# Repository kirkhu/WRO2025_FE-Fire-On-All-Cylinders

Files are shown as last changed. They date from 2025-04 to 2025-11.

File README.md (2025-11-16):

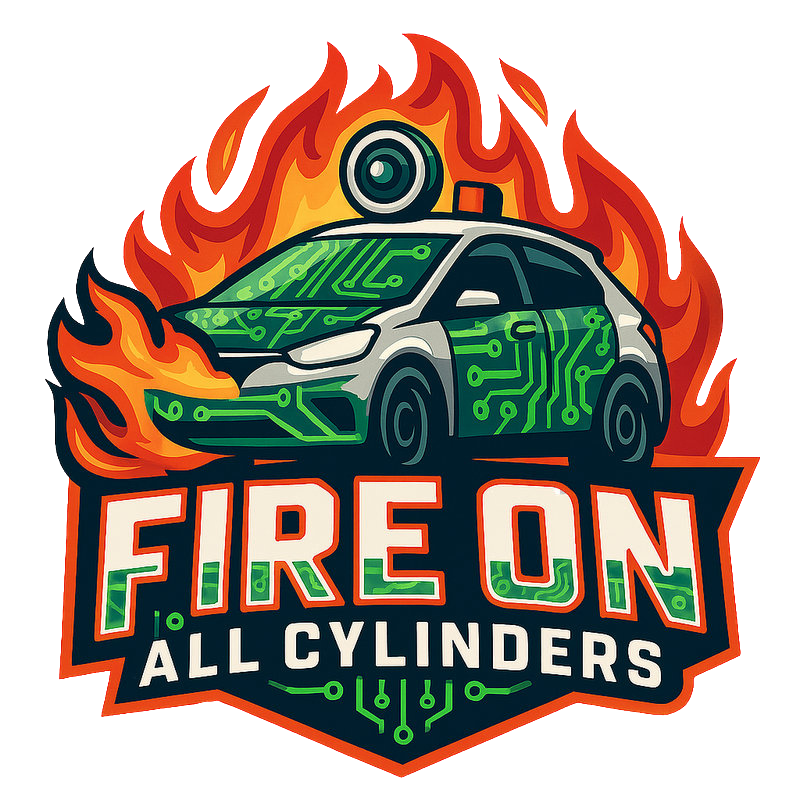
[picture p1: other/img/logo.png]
logo
 

### **Official Technical Document Introduction and Design Overview** 
- This is the official technical documentation for the WRO Taiwan National Team, **"Fire On All Cylinders."**
  
- You can find hyperlinks to the technical report content and setup instructions here, provided for quick access by both learners and judges during study or evaluation.
  
- This technical document will feature a detailed table of contents structured **according to the official scoring criteria** (such as the engineering journal evaluation rubrics), with all section titles displayed as **hyperlinks**. This allows judges or learners to easily navigate to the key content of the technical documentation for **rapid and efficient evaluation**.

### **Autonomous Car Design: Key Upgrades and Iterations** 

 - This autonomous vehicle design is built upon the wealth of experience inherited from our **predecessor team ("Shinan-Fire-On-All-Cylinders")** and integrates the practical experience gained from our participation in the **World Final last year**. Not only have we **drawn lessons from the successful elements of last year's champion team**, but we have also implemented critical technical iterations:
  
    * **Controller Upgrade:** The main controller has been upgraded from the standard **Jetson Nano** to the superior performance of the **Nvidia Jetson Orin Nano**.
    * **Mechanical Overhaul:** We have reorganized and optimized the vehicle's mechanical components, focusing specifically on the **steering system** and the **chassis**.
    * **Visual Enhancement:** Image processing capabilities have been significantly improved, achieving higher **efficiency and accuracy**.
    
    The integration of all these upgrades and innovative design elements is aimed at **comprehensively enhancing the vehicle's overall performance and competitiveness**.

**Special Note:**
- Due to network speed fluctuations, some images may not display correctly. Should this occur, please try refreshing the page to resolve the issue.

#### [For Learners](learners_contents.md)

## Rubric for Judging Engineering Documentation

- ###  ${{\color{red} Hardware Overview }} $ 
  #### 1. Mobility Management
    * [1-1 Vehicle 2D/3D Models in CAD](models/Vehicle_2D_3D/README.md)
    * [1-2 Vehicle Chassis Design](schemes/Vehicle_Chassis_Design/README.md)
    * [1-3 Motor Selection](schemes/Motor/README.md)
  #### 2. Power and Sense Management
    - __2-1 Vehicle Design__
      - [2-1-1 BOM Pats List](schemes/Parts_List/README.md)
      - [2-1-2 Circuit Design](models/Circuit_Design/README.md)
      - [2-1-3 Hardware Fool-Proof Design](schemes/Fool-Proof-Design/README.md)
      - [2-1-4 Assembly Instructions & Wiring Diagrams](schemes/Assembly_Instructions/README.md)
    - __2-2 Power Management__
      - [2-2-1 Battery choice for self-driving cars](schemes/Battery/README.md)
      - [2-2-2 Power Supply System](schemes/Power_Supply_System/README.md)
    - __2-3 Controller Selection__
      - [2-3-1 Main Controller Comparison](schemes/Main_Controller_Choosing/README.md)
      - [2-3-2 Motor & Sensor Intermediate I/O Controller Comparison](schemes/Motor_Sensor_Controller_Choosing/README.md)
    - __2-4 Sense Management__
      - [2-4-1 Ultrasonic rangefinder](schemes/HC-SR04/README.md)
      - [2-4-2 Infrared Sensor](schemes/Infrared-Sensor/README.md)
      - [2-4-3 Gyroscope orientation sensor](schemes/BNO055/README.md)
      - [2-4-4 Camera Selection](schemes/Camera/README.md)

- ### ${{\color{red} Software Overview }} $ 
  #### 3. Obstacle Management
    - [3-1 Software Platform Construction](src/System_Platform_Software/README.md)
    - [3-2 OpenCV Introduction](src/OpenCV/README.md)
 
    - __3-3 Image Recognition Processing and Steering__
      - [3-3-1 Image Recognition Processing](src/Image_Recognition_Processing/README.md)
      - [3-3-2 Parking Lot Departure Steering Control Overview](src/Overview_of_Parking_Lot_Departure_Steering_Control/README.md) 
      - [3-3-3 Steering Control](src/Steering_Control/README.md) 
      - [3-3-4 Automatically record the LAB values of the field](src/Automatically_record_LAB/README.md)
    - __3-4 Programming - Vehicle’s control program__
      - [3-4-1 Open Challenge Code Overview](src/Programming/Open_Challenge/README.md)
      - [3-4-2 Obstacle Challenge Code Overview](src/Programming/Obstacle_Challenge/README.md)
      - [3-4-3 Vehicle Departure Procedure Guide](src/Vehicle_Departure_Procedure_Guide/README.md)
      - [3-4-4 Vehicle Parking Procedure Guide](src/Vehicle_Parking_Procedure_Guide/README.md)
    - __3-5 Remote Connection__
      - [3-5-1 NoMachine software Introduction](other/NoMachine/README.md)

- ### ${{\color{red} Other}} $
  #### 4. Pictures – Team and Vehicle
    - [4-1 Team Members Introduction](t-photos/README.md)
    - [4-2 Vehicle Photos](v-photos/README.md)  
  #### 5. Performance Videos - Challenge rounds
    - [5-1 Open Challenge rounds](video/Open_Challenge/video.md)
    - [5-2 Obstacle Challenge rounds](video/Obstacle_Challenge/video.md)
    - [5-3 Self-Driving Car Design Process Video ](video/Design_Process_Video/video.md)

  #### 6. GitHub Utilization-GitHub
    - [6-1 GitHub Editing Tools Introduction (VScode Edit/GIT)](src/GitHub_Edit/README.md)
    - [6-2 GitHub Web Editor Supported Markup Languages](src/GitHub_Languages/README.md)  
  #### 7. Engineering Factor
    - [7-1 Learning Journey](other/Learning_Journey/README.md)
      - [February](other/Learning_Journey/README.md#20250228--20250307)
      - [March](other/Learning_Journey/README.md#20250308--20250321)
      - [April](other/Learning_Journey/README.md#20250322--20250404)
      - [May](other/Learning_Journey/README.md#20250426--20250502)
      - [June](other/Learning_Journey/README.md#20250531--20250606)
      - [July](other/Learning_Journey/README.md#20250628--20250704)
      - [August](other/Learning_Journey/README.md#20250712--20250822)
      - [September](other/Learning_Journey/README.md#20250830--20250905)
      - [October](other/Learning_Journey/README.md#20250927--20251003)
      - [November](other/Learning_Journey/README.md#20251101--20251107)

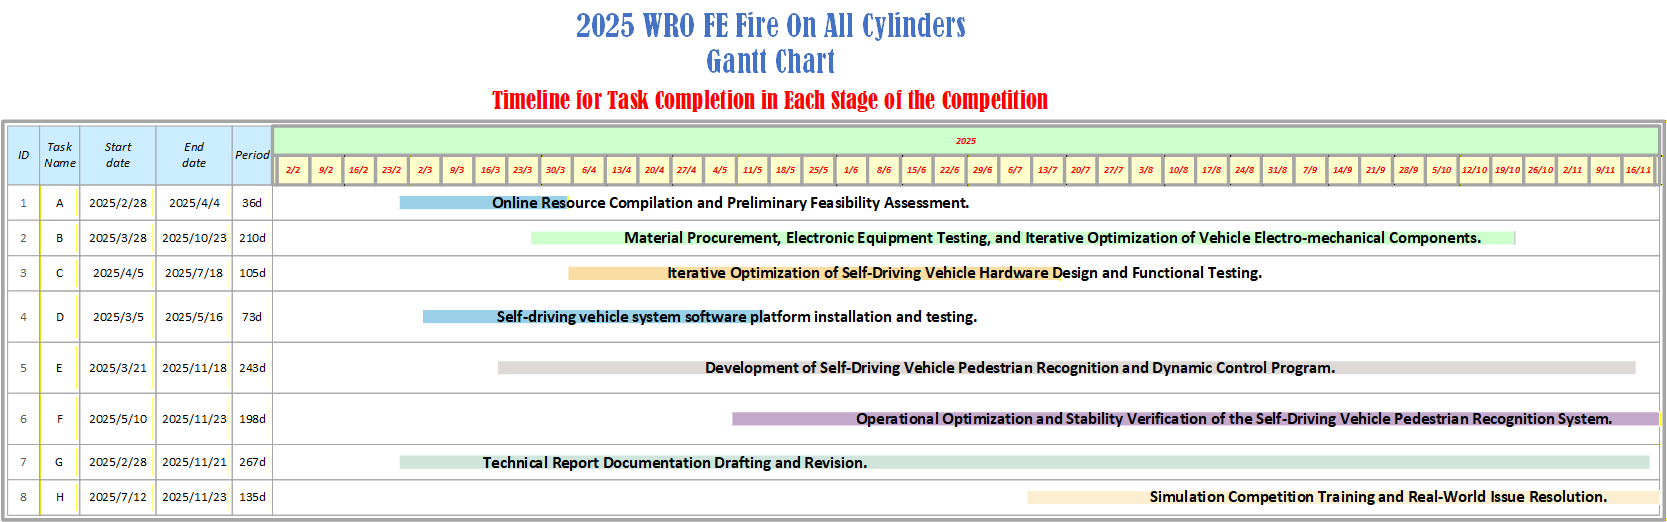
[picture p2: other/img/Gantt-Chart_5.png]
Gantt-Char


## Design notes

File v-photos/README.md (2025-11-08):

<div align="center">logo</div>

## <div align="center"> Vehicle's photos</div>
- ### Vehicle's photos
<div align="center">
<table>
  <tr align="center">
    <th>Top View</th>
    <th>Bottom View</th>
  </tr>
    <tr align="center">
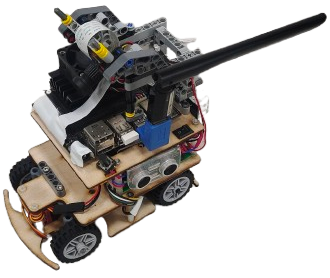
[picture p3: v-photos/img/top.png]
Top view
    <td> </td>
    <td>Bottom view</td>

  </tr>
    <tr align="center">
    <th>Front view </th>
    <th>Rear view</th>
  </tr>
    </tr>
    <tr align="center">
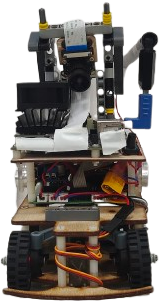
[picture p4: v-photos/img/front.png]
Front_view
    <td></td>
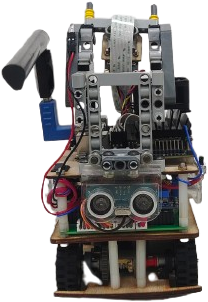
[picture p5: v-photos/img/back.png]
Rear_view
    <td></td>
  </tr>
  </tr>
    <tr align="center">
    <th>Left view</th>
    <th>Right view</th>
  </tr>
    </tr>
    <tr align="center">
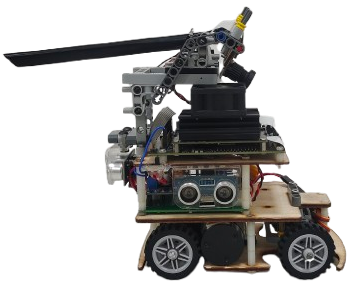
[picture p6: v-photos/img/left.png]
Left view
    <td></td>
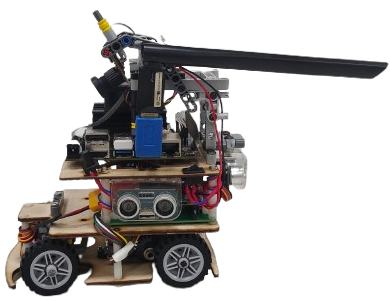
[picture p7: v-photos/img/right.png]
Right view
    <td></td>
  </tr>
</table>
</div> 

- ### Vehicle Body Structure Display Diagram
  <div align="center">
  <table>
    <tr>
    <th>Top View of the Overall Apparatus
    </th>
    <th>Middle Layer Structure Top View</th>
    <th>Top View of Vehicle Chassis</th>
    <th>Bottom View of Vehicle Chassis</th>
    </tr>
    <tr align="center">
      <td>  Top View of the Overall Apparatus
      </td>
      <td>Middle Layer Structure Top View
      </td>
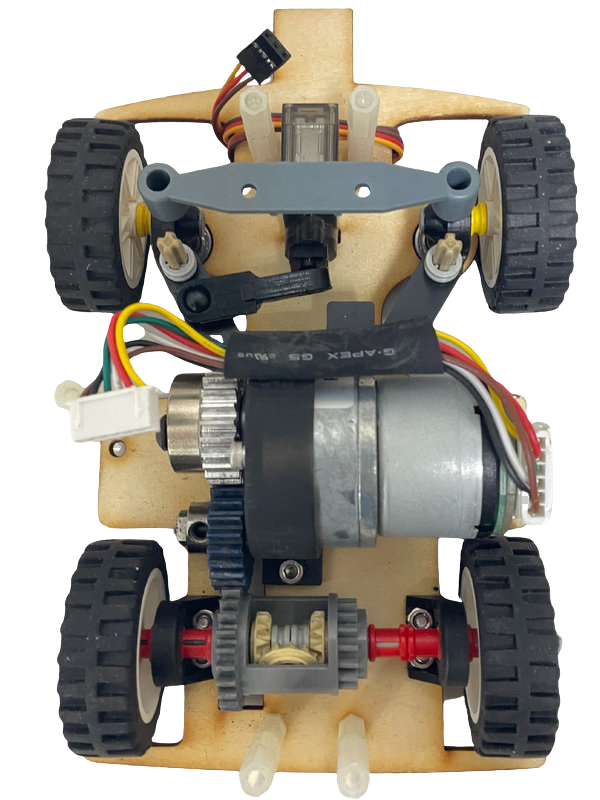
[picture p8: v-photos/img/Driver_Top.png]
Top View of Vehicle Chassis
      <td>
      </td>
      <td>Bottom View of Vehicle Chassis</td>
    </tr>
  </table>
  </div>
- ### Circuit Board
    <div align="center">
    <table>
      <tr align="center">
          <th> Overhead view of the main circuit board</th>
          <th>Overhead view of the switch circuit board</th>
      </tr>
      <tr align="center">
        <td> circuit_up </td>
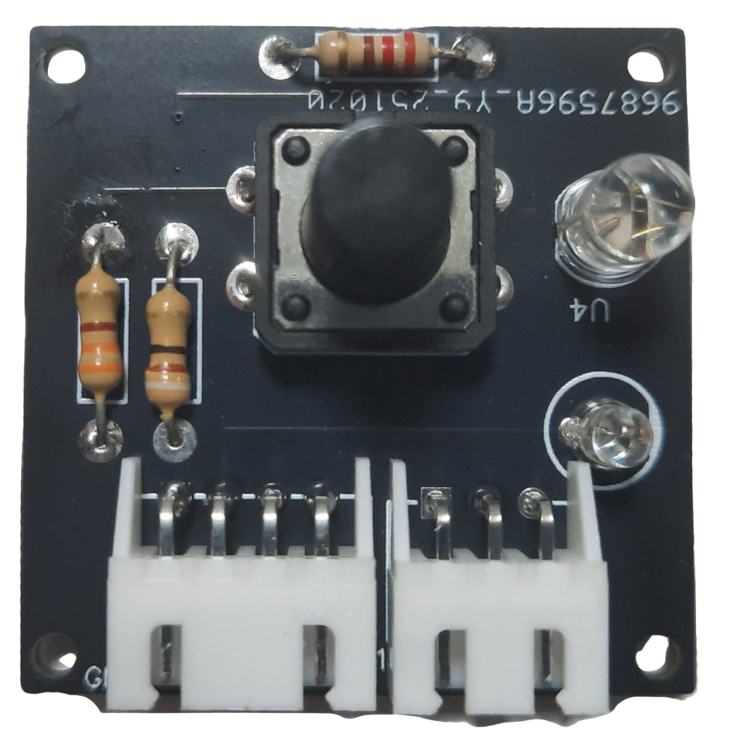
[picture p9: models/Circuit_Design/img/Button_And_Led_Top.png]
circuit_lower
        <td></td>
      </tr>
    </table>
    </div>

# <div align="center">HOME[Return Home](../)</div>

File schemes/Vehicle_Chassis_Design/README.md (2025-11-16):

<div align="center">logo</div>

## <div align="center">Vehicle Chassis Design Process</div> 

### Hardware Design Philosophy and Chassis Optimization
  1.  **Design Legacy and Innovation:** The software and hardware design of this **Self-Driving Car** continues the inspiration from last year's model while **drawing upon the strengths of last year's world champion vehicle design**. Building on this foundation, we upgraded the main controller from the **Nvidia Jetson Nano to the Nvidia Jetson Orin Nano**. This move not only significantly enhances the overall computational performance but also provides a robust basis for introducing innovative software designs, making the vehicle more competitive.

  2.  **Steering Geometry Improvement:** The chassis structure utilizes the common engineering principle of **Ackermann Steering Geometry**. Crucially, we implemented **improvements based on the shortcomings of last year's mechanism**, ensuring the vehicle performs **obstacle avoidance** and **turning maneuvers** with greater stability and smoothness.
  
  3.  **Autonomy of Core Components:** The **vehicle chassis** used in this competition was **independently designed and developed** by our team.
  
- ### Vehicle Chassis Improvement Record

  <div align=center>
  <table>
  <tr>
  <th >2024 Season Competition Self-Driving Car Prototype</th>
  <th  colspan=2 >2025 WRO World Final Competition Prototype</th>
  </tr>
  <tr align=center>
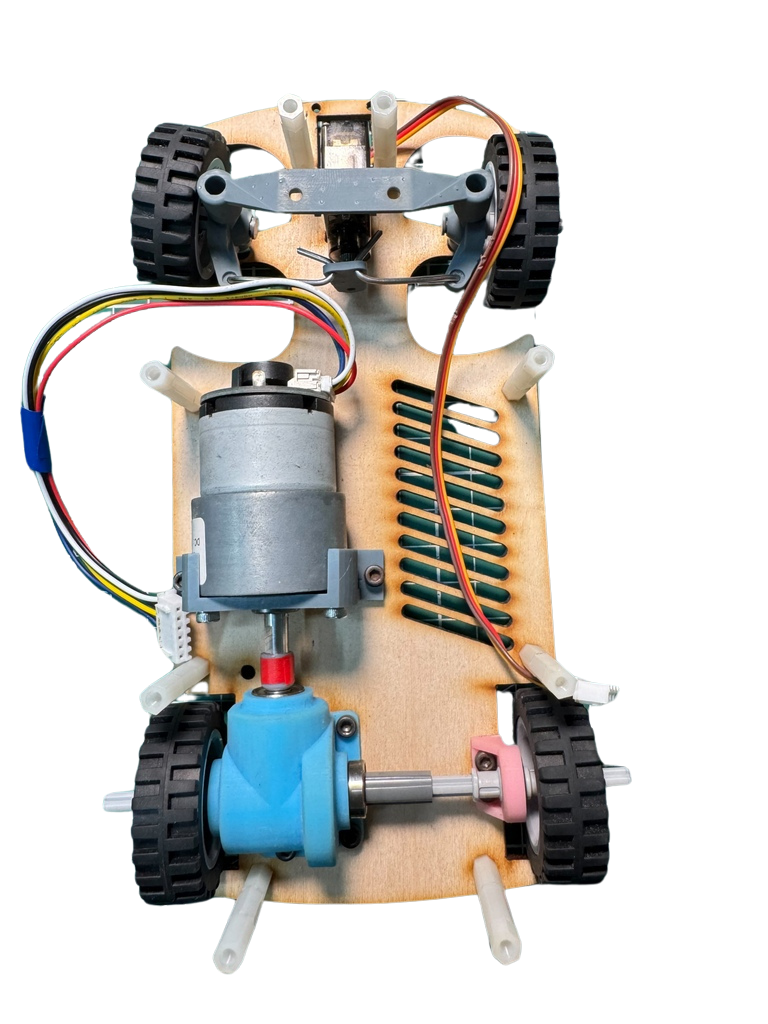
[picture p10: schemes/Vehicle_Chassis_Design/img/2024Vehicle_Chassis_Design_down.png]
2024 Season Competition Self-Driving Car Prototype
  <td width="33%"></td>
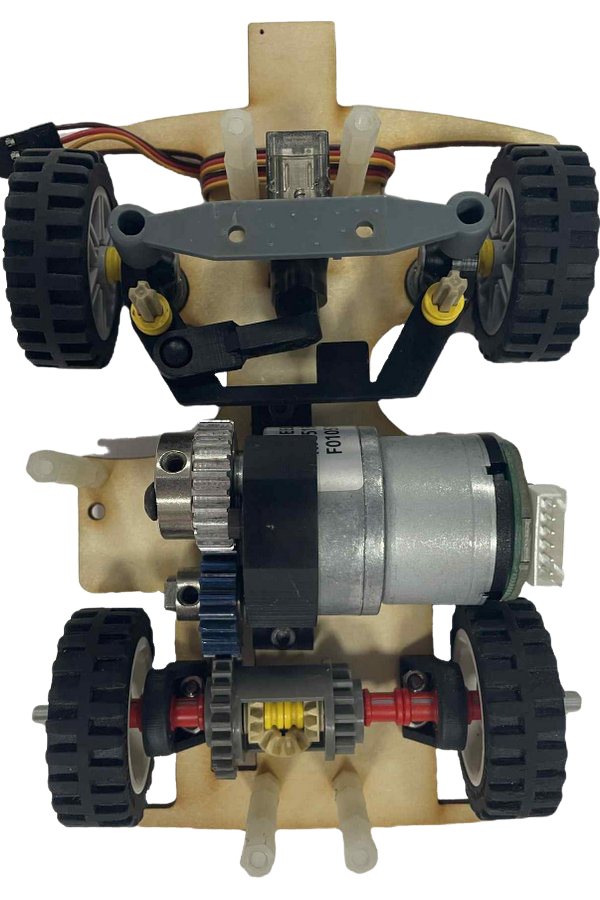
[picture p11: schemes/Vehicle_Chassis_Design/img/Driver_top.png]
  <td width="34%"></td>
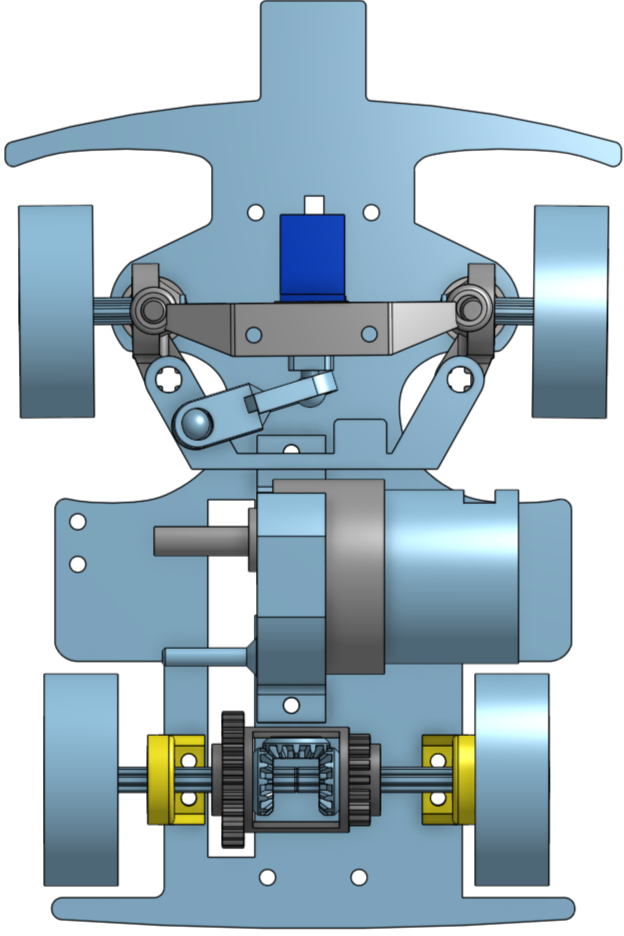
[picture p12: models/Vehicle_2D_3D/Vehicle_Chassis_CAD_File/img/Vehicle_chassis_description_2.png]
  <td width="33%"></td>
  </tr>
  <tr>
  <th colspan=3>Description</th>
  </tr>
  <tr>
  <td colspan="3">

#### **Major Changes in Model and Functionality**

From the previous year's version to this year's international competition version, our model design underwent several key optimizations:

* **Model Size Optimization:** Since the vehicle model was too long, it frequently **moved the field pillars/blocks during obstacle avoidance**. We **shortened the overall length of the model** to enhance obstacle clearance stability.
* **Main Controller Upgrade:** During the National Competition, we found that the **Jetson Nano's computing efficiency** was insufficient for our needs. Consequently, we replaced the main controller with the **higher-computing-efficiency Jetson Orin Nano**.
* **Steering Structure Redesign (I):** Last year's international model used **metal wires** to link the two steering knuckles, which **occupied a large area** and was inefficient. We therefore **redesigned the entire steering structure using 3D printed components**.
* **Steering Structure Redesign (II):** The autonomous vehicle's **steering angle was insufficient**, preventing it from navigating certain **sharp turns**. We **redesigned the steering structure** to allow for a **larger steering space**, enhancing its maneuverability.
* **Addition of Parking Assistance Sensors:** We **added TCRT5000 infrared sensors to the front and rear** of the vehicle, specifically dedicated to **assisting the precision of the parking procedure**.

#### **The Four Iterations of Chassis Design**

Our chassis design underwent a total of four iterations:

1.  **First Iteration:** **Arc-shaped chamfers** were added to the front of the car to prevent the front wheels from **getting stuck** when contacting the side walls, improving self-extrication capabilities after collision.
2.  **Second Iteration:** We **enlarged the mounting holes for the steering knuckles** and **switched to using bearings** to reduce friction, making the steering process **smoother**.
3.  **Third Iteration:** We **reduced the gap** between the steering structure and the motor brackets, and **shortened the wheelbase** to **increase the steering angle** (reducing the turning radius).
4.  **Fourth Iteration:** A **small rectangular block was extended** from the front of the car, specifically to **protect the infrared sensors** from damage during wall collisions.

  </td>
  </tr>
  </table>
  </div> 

**Final Version Vehicle Chassis Design and Physical Product Correspondence**

- The table below presents the clear correspondence between the 3D Model and the final manufactured physical product of our final design version of the Vehicle Chassis.

  |3D Vehicle Chassis Design| Vehicle Chassis Top View | Vehicle Chassis Bottom View|
  |:----:|:----:|:----:|
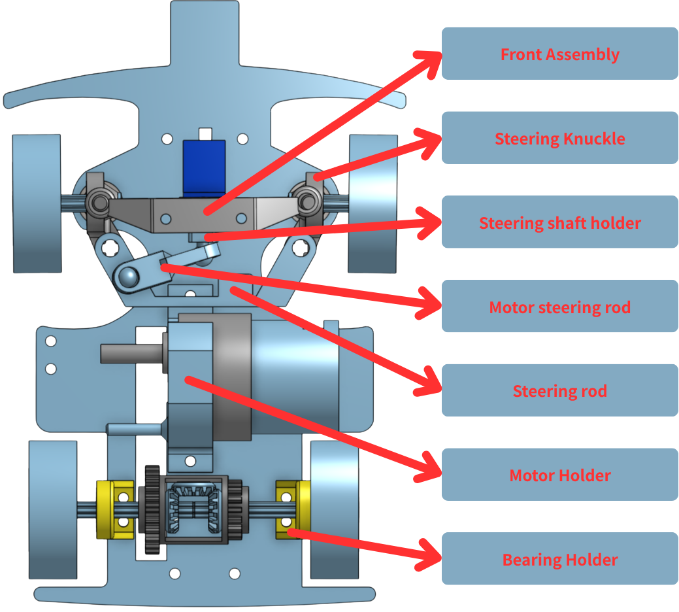
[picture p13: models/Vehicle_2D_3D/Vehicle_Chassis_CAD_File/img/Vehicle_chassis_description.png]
vehicle_chassis_design_3D
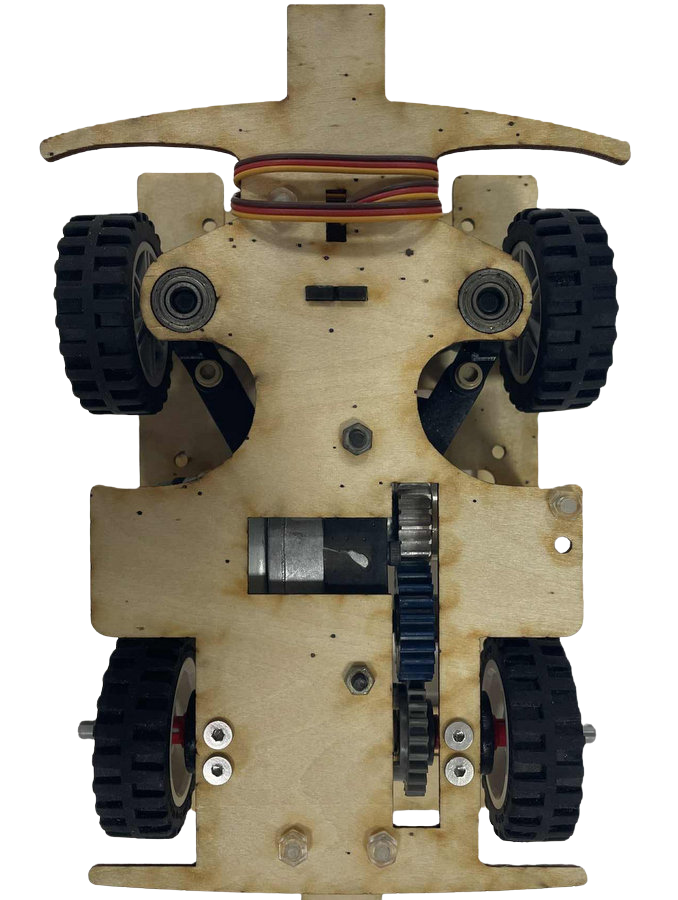
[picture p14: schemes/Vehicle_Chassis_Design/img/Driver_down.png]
down_view
  ||2024Vehicle_Chassis_Design_down||

  - We customized the design of component dimensions and shapes based on the specific performance requirements of the autonomous vehicle. Utilizing a Stereolithography (SLA) 3D printer and a laser cutting machine, we self-designed and manufactured all parts of the vehicle chassis, excluding the gears, the LEGO 6573 differential gear, and the tires.

  - To significantly reduce the rotational friction of the bearings, we - precisely integrated them into the vehicle's support structure (bracket), a mechanical optimization that effectively enhanced the vehicle's overall driving speed.

  - In order to precisely control the vehicle's optimal turning radius and flexibly adjust the Ackermann ratio, we employed 3D modeling techniques and a Stereolithography (SLA) 3D printer to custom-design the critical components and vehicle brackets for the Ackermann steering geometry structure according to specific needs.

**Evolution of the Ackermann Steering Geometry Structure**
  <div align=center>
  <table>

  <tr>
    <th colspan=2>First Generation Steering Structure (V1.0)</th>
  </tr>
  <tr>
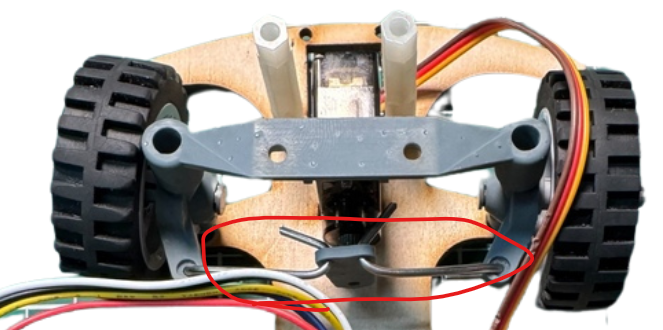
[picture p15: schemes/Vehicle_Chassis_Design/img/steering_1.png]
  <td width=40%></td>
  <td width=60%>

  This version of the steering structure was designed to be overly wide, and the steering rod was made from drawn metal wire, which was difficult to fix into shape, impacting accuracy.

  </td>
  </tr>
  <tr>
    <th colspan=2>Second Generation Steering Structure (V2.0)</th>
  </tr>
  <tr>
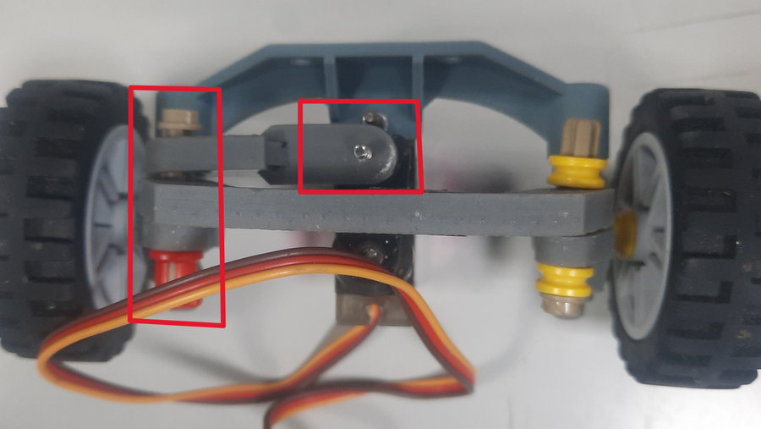
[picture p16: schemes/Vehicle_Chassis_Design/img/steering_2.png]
  <td width=40%></td>
  <td width=60%>
To solve the V1.0 structure's bulkiness and accuracy issues, in V2.0 we:

  - Reduced the overall template size.

  - Replaced the metal wire steering rod with a 3D printed component, significantly improving the rod's accuracy and enhancing the self-driving car's steering agility. However, the use of screws to connect LEGO parts in this version still constrained the steering angle. Therefore, the next iteration (V3.0) will switch to rounded cross axles and Ball Joint Steering Shaft Holder to increase the steering range.
  </td>
  </tr>
  <tr>
    <th colspan=2>Third Generation Steering Structure (V3.0)</th>
  </tr>
  <tr>
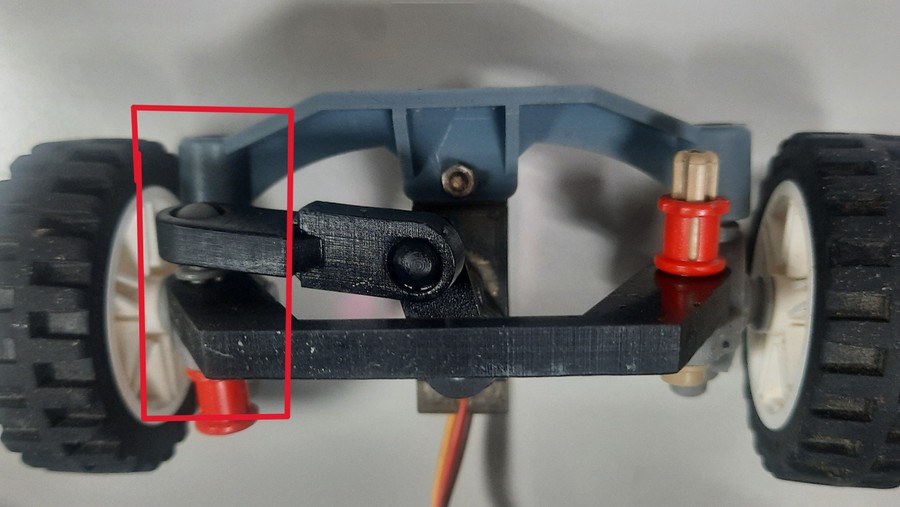
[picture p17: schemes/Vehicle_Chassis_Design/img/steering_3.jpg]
  <td width=40%></td>
  <td width=60%>
  This version encountered steering torque issues during testing, leading us to re-examine the design blueprint. The next version (V4.0) will incorporate the following fixes:

  - Adjust the connection point of the steering tie rod and linkage to be parallel with the rounded steering rack, optimizing mechanical performance.

 - Add a steering limit block to prevent the structure from collapsing inwards due to excessive steering angles.
  </td>
  </tr>
  <tr>
    <th colspan=2>Fourth Generation Steering Structure (V4.0)</th>
  </tr>
  <tr>
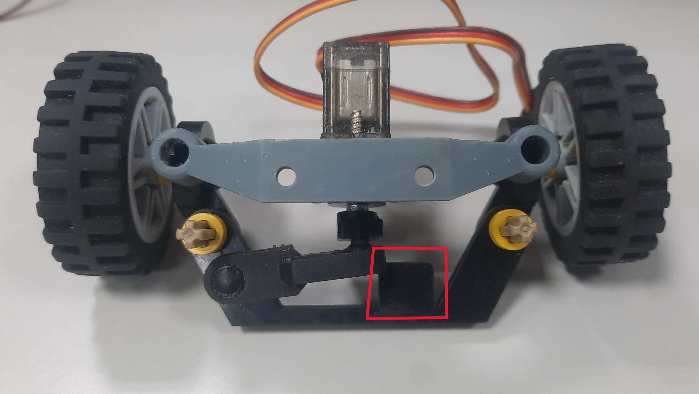
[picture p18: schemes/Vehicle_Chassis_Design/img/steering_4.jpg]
  <td width=40%></td>
  <td width=60%>

  The newly added steering limit block in this version was oversized, which inadvertently restricted the steering angle and reduced the steering agility. Therefore, in the subsequent version (V5.0), we will shorten the limit block to balance both the steering amplitude and structural protection.
    </td>
    </tr>
  <tr>
    <th colspan=2>Final Version Steering Structure (V5.0)</th>
  </tr>
  <tr>
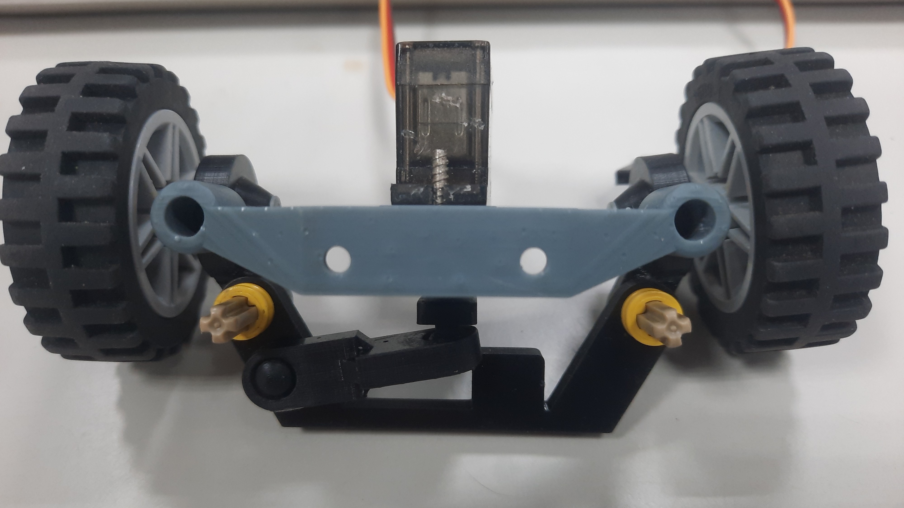
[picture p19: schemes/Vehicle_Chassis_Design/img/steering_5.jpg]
    <td></td>
    <td width=400>
   Following continuous correction and optimization across the previous generations, the current steering structure fully meets the performance requirements of our vehicle model, achieving a stable design state.
    </td>
  </tr>
  </table>
  </div>

- ####  Selection and Modification of LEGO Differential Gears

  The gear differential is a critical core component of a vehicle's drivetrain , used to balance and precisely distribute power to the driving wheels.

  It enables the driving wheels to rotate at different speeds , which is especially crucial during turns. The differential achieves this function through a series of precisely engineered gear mechanisms , allowing the two driving wheels to adaptively adjust their rotational speeds. This capability is vital for enhancing the vehicle's agility and handling. Regardless of road conditions, the differential ensures the vehicle's stability and balance, thereby maintaining excellent driving performance.

  - #### Application and Comparison of LEGO Differential Gears
      In this competition, we utilized LEGO differential gears to implement the core functions of vehicle driving and turning. These differential gears primarily come in two models: the LEGO 6573 Differential and the LEGO 62821 Differential.

    __LEGO 62821 Differential__
      - Composition: This differential consists of one 28-tooth outer gear and four LEGO 12-tooth bevel gears (part number 4565452).

      - Design Advantages: Its compact, enclosed casing design enhances durability and torque transfer efficiency. The central structure securely holds the bevel gears in place, ensuring smooth power distribution to the two output shafts.

      - Performance Positioning: This makes it more efficient and reliable than the older LEGO 6573 Differential.

    __LEGO 6573 Differential__
      - Composition: This differential integrates one 16-tooth gear and one 24-tooth gear. Both gears feature a 5 mm diameter hole at their center for easy cross axle installation.

      - Structural Features: The center of the differential includes a small pillar designed to better secure the right-angle bevel gears, and it can be used in combination with three LEGO 12-tooth bevel gears (part number 4565452).

      <div align=center>
          <table>
          <tr align=center>
          <th>LEGO 62821 GearDifferential</th>
          <th >LEGO 6573 Gear Differential</th>
          </tr><tr align=center>
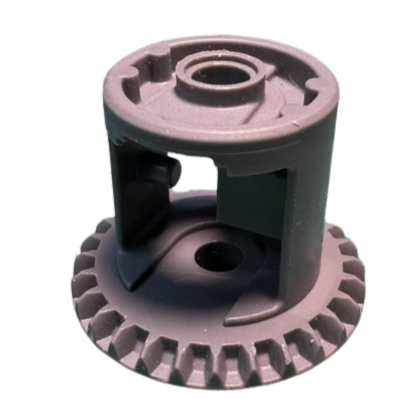
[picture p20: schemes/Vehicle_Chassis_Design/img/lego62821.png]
          <td></td>
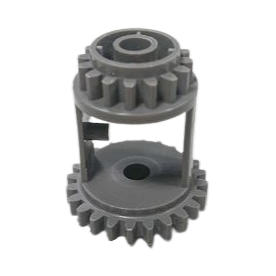
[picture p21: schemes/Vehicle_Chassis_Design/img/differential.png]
          <td></td>
          </tr>
          </table>
          </div>

  - #### Reason for Selection

    - We initially incorporated the LEGO 62821 differential gear as a component in our steering system. However, during the process of meeting the design goal of reducing the chassis dimensions, we discovered that this differential occupied excessive space, making it incompatible with the new structural constraints.

    - Consequently, despite the LEGO 62821 differential gear offering superior steering performance, we chose to abandon it in favor of the smaller LEGO 6573 differential gear. This substitution successfully resolved the structural issue related to the required chassis size reduction, allowing us to achieve a compact vehicle design.

        <div align="center">
        <table>
        <tr>
        <th>LEGO 62821 Gear Differential </th>
        <th>LEGO 6573 Gear Differential </th>
        </tr><tr align=center>
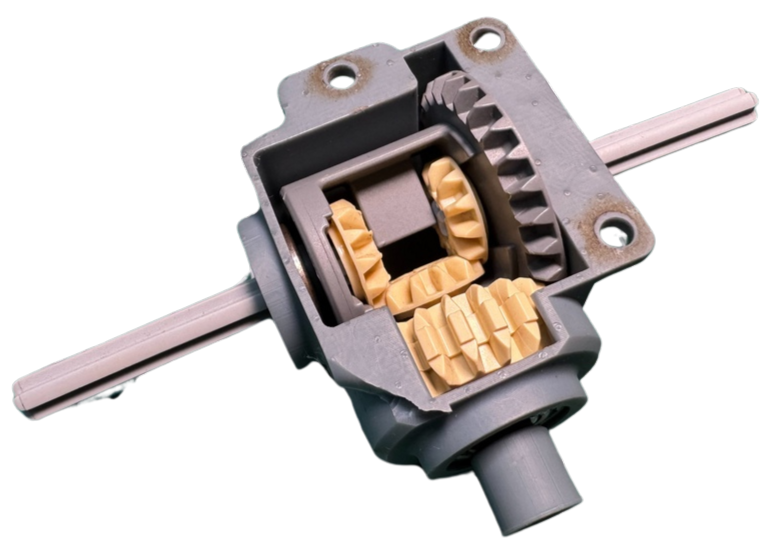
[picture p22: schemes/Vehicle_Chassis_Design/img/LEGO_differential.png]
        <td></td>
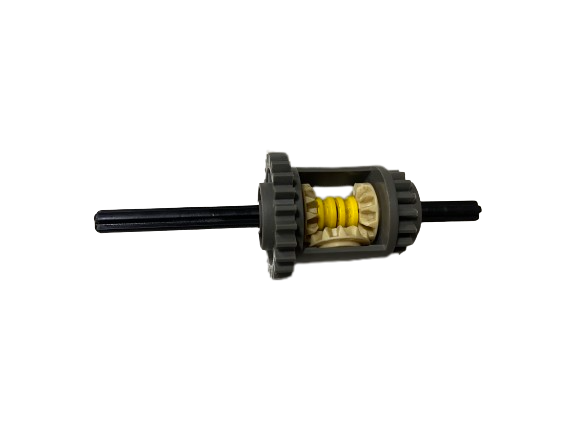
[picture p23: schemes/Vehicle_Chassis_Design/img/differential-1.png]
        <td></td>
        </tr>
        </table>
        </div>

- ### Supplementary information

   - #### What is an Ackermann Steering Geometry?
     __Ackermann Steering Geometry Introduction__
      - The Ackermann steering geometry, proposed by German automotive engineer Lankensperger in 1817, is a steering system design used in automobiles. It was developed to address the geometric discrepancy in the paths of the inner and outer turning wheels when a vehicle makes a turn.
      - People apply Ackermann steering geometry to the steering mechanism of vehicles. Through the corresponding cranks of the four-linkage system, the steering angle of the wheels relative to the projected tire is increased by about 2 to 4 degrees. This results in the rough convergence of the trajectory centers of all four wheels along the extension line of the rear axle, thereby achieving the vehicle's turning.
      
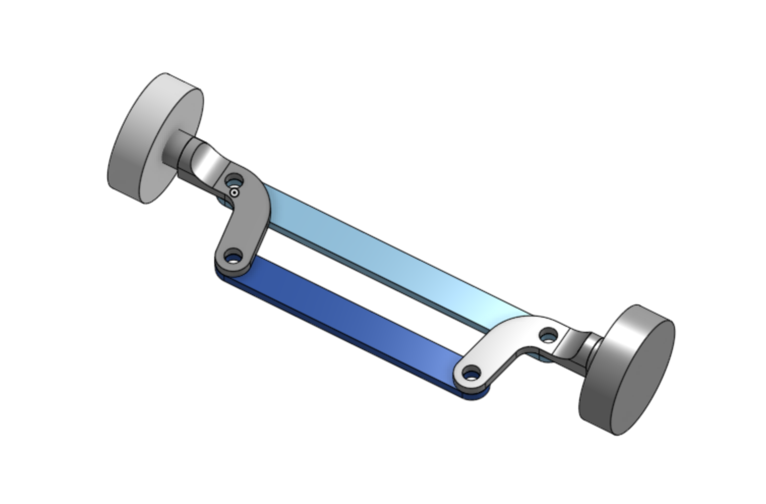
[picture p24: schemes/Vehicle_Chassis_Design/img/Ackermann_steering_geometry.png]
Ackermann_steering_geometry
        

      Reference Link：[Ackermann steering geometry@Wikipedia](https://zh.wikipedia.org/zh-tw/%E9%98%BF%E5%85%8B%E6%9B%BC%E8%BD%89%E5%90%91%E5%B9%BE%E4%BD%95)
      
    -  #### The principle of Ackermann steering geometry is based on the following concepts:     
       - __Difference in Turning Radius:__ When the vehicle makes a turn, the two front wheels need to rotate at different angles to allow the vehicle to pivot around a central point.
       - __Turning Angles of the Two Front Wheels:__ The design of the Ackermann steering geometry ensures that both front wheels pass through a central point simultaneously during steering.
    - Compared to the Ackermann steering geometry made from the original 0% LEGO bricks, the steering mechanism of this competition vehicle is designed with reference to an 80% Ackermann steering geometry. It offers advantages such as reduced resistance and smoother turns. The Ackermann steering geometry parts are produced using a stereolithography (SLA) 3D printer. However, the most challenging aspect of the process was adjusting the Ackermann ratio to achieve the ideal turning angle for our vehicle to navigate around blocks effectively.  

  - #### Why Choose an 80% Ackermann Ratio?
    - In theory, this design is the optimal choice for smooth and efficient turns. However, it may lead to excessive tire wear. Therefore, in automobile design, a 100% Ackermann ratio is usually not chosen. Compared to a 100% Ackermann ratio, an 80% Ackermann ratio allows for smoother, more predictable turns, improves maneuverability, and reduces tire wear.
  
    - #### Calculating the Ackermann Angle Graphically (a-b = ack)
    <div align="center">
    <table>
    <tr align=center>
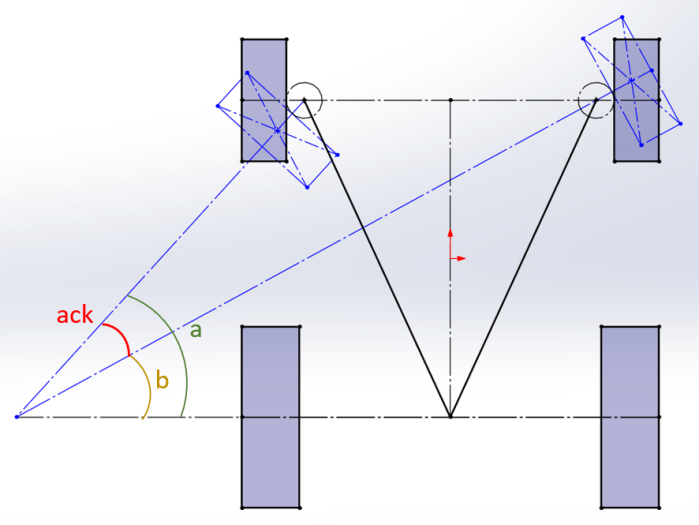
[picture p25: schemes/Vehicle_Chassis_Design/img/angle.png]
angle
    <td width="30%"></td>
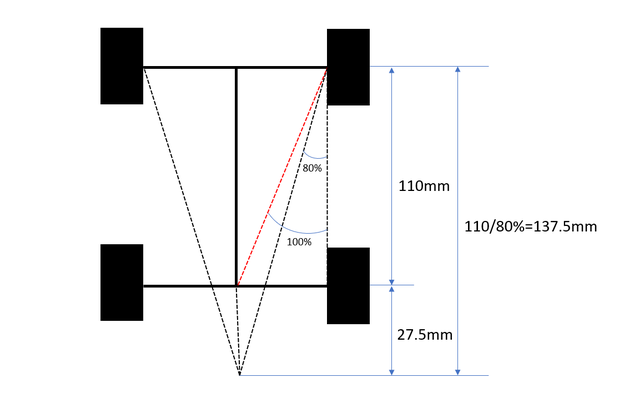
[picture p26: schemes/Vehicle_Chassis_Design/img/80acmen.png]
Ackermann_steering_geometry_lego
    <td width="30%"></td>
    </tr>
    </table>
    </div>

    Reference Video website：[汽车转弯 没那么简单: 阿克曼转向几何是个啥？How does Ackerman steering geometry work?](https://www.youtube.com/watch?v=8AimxDPWKcM)

# <div align="center">HOME[Return Home](../../)</div>

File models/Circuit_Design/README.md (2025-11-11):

<div align="center">logo</div>

 ## <div align="center"> Circuit Design </div>

- In the design process of our **Self-Driving Car** circuit board, we utilized **EasyEDA**, a professional circuit design software featuring an **intuitive graphical interface**. Through this tool, we have **significantly enhanced** the **accuracy** of soldering and the **precision** of wiring, thereby **effectively reducing** the error rate during the manufacturing process, and minimizing the **risk of component burnout**.

- We adopted a **professional Printed Circuit Board (PCB) manufacturing method** (i.e., "PCB etching/fabrication"). This approach has not only **substantially mitigated** the **potential risks** of soldering errors and short circuits but has also **improved the aesthetic quality of the finished product**. Concurrently, this manufacturing technique offers **greater process flexibility** and **operational convenience**.

- The **core function** of this circuit board is to provide a stable and reliable **power supply** and **signal transmission interface** for the **integrated** various **sensors**, **motors**, and the **upper and lower layer controllers**. This ensures that all critical electronic components can achieve **smooth communication** and **efficient collaborative operation**, laying a solid foundation for the execution of the **Vehicle's control program**.

 - ### The Process of Identifying and Correcting Physical Circuit Board Design Issues 
   - ### Circuit Design Optimization and Iteration
   The circuit design for this project underwent several versions to achieve maximum performance and reliability:
<div>
<table>
   <tr>
      <th colspan=3 >Initial Phase and Fundamental Design Flaws V1.0 (Pegboard)</th>
   </tr>
   <tr>
      <td align=center  width="25%"></td>
      <td align=center  width="25%"></td>
   <td>

   __Description:__          

   - This design utilized a PCB pegboard (also known as a universal PCB) as the material for circuit construction. However, this choice resulted in an extremely time-consuming process for circuit design and soldering. Furthermore, the wiring layout appeared cluttered, lacking systematic planning and aesthetic quality. This not only severely hindered the efficiency of subsequent debugging and fault diagnosis, but also posed significant circuit reliability risks, including issues like cold solder joints, poor soldering, and short circuits.
               
   </td>
   </tr>
   <tr>
      <th colspan=3>Adopting Professional Fabrication and Discovering Parameter Errors V2.0 (PCB)</th>
   </tr>
   <tr>
      <td align=center width="25%" ></td>
       <td align=center  width="25%"></td>
      <td>

   __Description:__

   - In order to resolve the various issues present in the old circuit board design (V1.0), we utilized EasyEDA software to redraw the circuit and generate a new Printed Circuit Board (PCB) layout (V2.0). We then submitted this design for professional manufacturing at a factory. This comprehensive process allowed us to successfully acquire industry-standard knowledge of PCB design and fabrication.

   - The team was highly excited upon receiving the factory-produced V2.0 PCB. However, during the component installation phase, we discovered that the electronic components could not be properly assembled. After careful inspection and verification, we confirmed that this was a design error caused by incorrectly setting the component's pin header pitch during the PCB design stage.
            
   </td>
   </tr>
   <tr>
      <th colspan=3>Critical Polarity Error and Subsequent Rectification V3.0 (PCB)</th>
   </tr>
   <tr>
      <td align=center width="25%"></td>
      <td align=center width="25%"></td>
   <td>

   __Description:__
      
   - Given the incorrect component pin pitch issue found in the previous PCB version (V2.0), we immediately referenced the standard example diagrams built into the EasyEDA software to precisely recalibrate the correct pin pitch parameters. We then sent this revised design (V3.0) to the factory for production.

   - However, upon receiving the factory-produced V3.0 PCB and proceeding with the functional testing phase, we discovered that the polarity of the entire circuit was reversed. After detailed circuit tracing and inspection, we ultimately confirmed that this problem stemmed from an operational error during the circuit board design stage: we mistakenly drew the trace layer that should have been on the bottom layer of the PCB onto the top layer.

   </td>
   </tr>
   <tr>
       <th colspan=3>Critical Polarity Error and Subsequent Rectification V4.0 (PCB)</th>
   </tr>
    <tr>
      <td align=center  width="25%"></td>
      <td align=center width="25%"></td>
   <td>

   __Description:__

   - Addressing the issue of reversed circuit polarity in the previous PCB version (V3.0), we performed a complete redraw of the schematic. Only after multiple strict verifications to ensure the design was correct did we submit the file for production, resulting in the accurate Printed Circuit Board (V4.0).

   - Subsequently, due to upgrading the robot's main controller to a Jetson Orin Nano and deciding to switch to infrared sensors for detecting proximity to the parking area walls, it became necessary to add two 2-Pin female connectors to the circuit board. Simultaneously, we redesigned the terminal blocks to provide a stable, plug-and-play power connection point for the Jetson Orin Nano. Based on these functional changes and upgrades, we were compelled to redesign the circuit and submit the new board version (V5.0) to the factory for re-printing.

   </td>
   </tr>
   <tr>
      <th colspan=3>Functional Upgrades and Final Circuit Architecture V5.0 (PCB)</th>
   </tr>
   <tr>
      <td align=center width="25%" ></td>
      <td align=center width="25%"></td>
   <td>
      
   __Description:__

- Correction of BNO055 Gyroscope Sensor Anomaly
Upon obtaining the new Printed Circuit Board (V5.0), testing revealed an intermittent issue where the BNO055 gyroscope sensor would return an angle reading of zero. Troubleshooting confirmed that this anomaly stemmed from the sensor's VCC/GND being supplied by the Raspberry Pi Pico W, while its signal lines were connected to the Jetson Orin Nano main controller. This configuration, where the power and signal sources were on different circuits (i.e., lacking a common ground reference), caused the sensor to malfunction. We immediately revised the design, ensuring that both the power and signal sources for the BNO055 gyroscope sensor are now supplied exclusively by the Jetson Orin Nano main controller to establish a stable electrical potential reference.

- Independent Switch Control Circuit Board (Secondary PCB)
Furthermore, to comply with the competition rule requiring the Jetson Orin Nano to detect the start button press before operation can begin, we designed a second, independent circuit board:
   - Start Button Integration: The start button circuit was independently connected to the Jetson Orin Nano's General-Purpose Input/Output (GPIO) interface, ensuring the main controller detects the start command as per regulations.
   - Debugging and Status Display: To optimize the debugging process, we added RGB LEDs to this board.
   - Functional Purpose: The LEDs are used to display the color of the nearest object detected by the vehicle in real-time, facilitating quick diagnostics and status monitoring.
   - This board is dedicated to the self-driving car's start button control and status indication.

   </td>
   </tr>
     </table>  
  </div>
     <table>
   <tr>
       <th colspan=4>Final Version(PCB)</th>
   </tr>
   <tr>
      <td align=center width="30%"></td>
      <td align=center width="30%"></td>   
      <td align=center width="20%"></td>
      <td align=center width="20%"></td>
   </tr>
      </table>

 - ### Circuit Schematic Drawing

   <table>
      <tr>
      <th colspan=3>Main PCB</th>
      </tr>
      <tr>
       <th>3D view</th>
       <th>circuit schematic</th>
       <th>PBC layout drawing</th>
      </tr>
      <tr>
       <td align=center width="30%"></td>
       <td align=center width="40%"></td>
       <td align=center width="30%" ></td>
      </tr>
      <tr>
      <th colspan=3>Secondary PCB(Switch Control Circuit Board )
      </tr>
      <tr>
       <th>3D view</th>
       <th>circuit schematic</th>
       <th>PBC layout drawing</th>
      </tr>
      <tr>
       <td align=center ></td>
       <td align=center ></td>
       <td align=center ></td>
      </tr>
   </table>

   <table>
   <th align=center>	Overall circuit schematic  </th>
   <tr>
   <td align=center width="100%">
   </td>
   </tr>
   </table>

 ***
 - ### Supplementary Information
 
 - #### Experience Sharing - BNO055 Gyroscope Sensor Circuit Design Error and Establishment of Common Ground Reference

   1. Initial Design Flaw: Lack of a Common Ground Reference
   In the initial design phase of the self-driving car's circuitry, the Adafruit BNO055 IMU sensor employed a distributed power model: its VCC/GND was supplied by the Raspberry Pi Pico W, while its data lines (signals) were connected to the Jetson Orin Nano main controller.

      This cross-device power and signal configuration, however, resulted in a serious design defect: the power loop failed to share a common ground (GND) with the signal loop. Consequently, the system lacked a unified electrical potential reference (Common Ground Reference). This electrical inconsistency was the root cause of the anomalous sensor data, specifically manifested as the Heading Angle output being stuck at 0° for extended periods, completely failing to reflect the vehicle's true attitude changes.

   2. The Solution: Correcting Power Path and Establishing a Common Ground
   To definitively resolve this circuit reliability issue, we revised the design scheme:

      - Unified Power and Signal Source: The Jetson Orin Nano was designated to directly provide the positive power to the BNO055 sensor.

      - Securing Common Ground: The sensor's ground line (GND) was connected directly to the Orin controller's GND pin.

      This critical adjustment ensured the closure of the power circuit and established a stable common ground reference between the two devices. Following this correction, the sensor data immediately returned to normal, and the heading angle accurately varied with the vehicle's rotation, fully meeting the high-precision requirements for autonomous vehicle localization and navigation control.

 - #### EasyEDA Introduction

   __EasyEDA__ is a free online Electronic Design Automation (EDA) software used for designing, simulating electronic circuits, and creating printed circuit boards (PCBs). It offers a simple and user-friendly graphical interface, with a variety of features that make it ideal for both hobbyists and professional engineers.
   - EasyEDA can be used directly in a web browser without the need for software installation, making it cross-platform accessible. It supports circuit design, simulation, PCB creation, and also allows teams to collaborate on electronic projects.
   - ### The main features of EasyEDA include:
     - Schematic Design: Design circuit diagrams using its extensive component library, which includes resistors, capacitors, transistors, integrated circuits (ICs), and more.
     - PCB Design: Supports multi-layer PCB design and provides an auto-routing feature to help users efficiently layout their boards.
     - Simulation: Built-in SPICE simulation allows users to virtually test circuits before manufacturing.
     - Component Library: Offers a vast component library and supports importing parts from other CAD tools or creating custom components.
     - Collaboration Tools: Allows users to share designs with teammates for collaborative work.
     - Cloud Storage: Design files can be saved in the cloud, making it easy to modify and access from anywhere, as well as facilitating collaboration with team members.
     - Manufacturing Integration: EasyEDA is seamlessly integrated with JLCPCB, allowing users to directly submit designs for production and easily order custom PCBs.

   ### Summarize

   __Overall, EasyEDA is a powerful and easy-to-use tool for electronic design. Whether you're a beginner or a professional engineer, it offers features to meet your needs. Its cloud-based accessibility, simple operation, and integration with manufacturers make it an excellent choice for designing and producing electronic circuits.__

   - Software link：[EasyEDA](https://easyeda.com/)
 <div align=center>
    <table>
    <tr>
    <th>EasyEDA of Official website.</th>
    <th>Schematic Design</th>
    </tr><tr>
    <td>EasyEDA of Official website.</td>
    <td>Schematic Design</td>
    </tr>
    </table>
    </div>

# <div align="center">HOME[Return Home](../../)</div>

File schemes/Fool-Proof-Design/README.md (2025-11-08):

<div align="center">logo</div>

## <div align="center">Hardware Fool-Proof Design</div>

- ####  Pin Header / Socket 
    During critical phases of hardware development and integration, we frequently encounter the risk of irreversible damage to high-value modules such as the __NVIDIA Jetson Orin Nano__, __Raspberry Pi Pico W__, and related Integrated Circuits (ICs) due to incorrect wiring of power or data signal lines. To effectively mitigate the severe consequences and __high costs associated__ with such human operational errors, we have proactively implemented key protective mechanisms in our design:

    - **Interface Standardization and Specification (Connectorization):** For power input and data transmission interfaces, we universally adopt standardized male and female connectors(Pin Header/Socket) to forcibly ensure correct orientation and connection, thus eliminating damage caused by incorrect insertion.

    - **Core Circuit Solidification Design:** Critical circuit components are directly soldered onto the Printed Circuit Board (PCB), achieving extremely stable, normatively laid-out management, which eliminates the potential weak points associated with external cable connections.

    This structural design optimization has significantly reduced the probability of failure in the core components of the NVIDIA Jetson Orin Nano and Raspberry Pi Pico W due to wiring mistakes, fundamentally enhancing the overall system's operational stability, long-term reliability, and effectively extending the product's Mean Time Between Failures (MTBF).

- #### pluggable terminal block
    To establish the power input solution for the __Jetson Orin Nano__, we have incorporated a __pluggable terminal block__ onto the main circuit PCB as its dedicated power supply interface.

    The rationale for this design choice is as follows:

    - **Power Path Requirement:** The Jetson Orin Nano relies on 11.1V lithium battery power supplied directly via the power socket and does not support reverse power delivery from its 5V pins.

    - **Connection Stability:** Directly connecting the power cable to a buck converter module carries the inherent risk of contact loosening, which could lead to unstable circuit power delivery and potentially damage the PCB.

    In summary, utilizing a pluggable terminal block as the interface for the power supply cable ensures connection stability and enhances overall system safety, while also facilitating subsequent maintenance and troubleshooting operations.

<div align=center>
    <table>
        <tr>
            <th>Pluggable Terminal Block(Power supply Terminal Block)</th>
            <th>Actual Photo of the Circuit(Power supply)</th>
        </tr>
        <tr align=center>
            <td>Terminal block</td>
            <td>Circuit</td>
        </tr>
    </table>
</div>

<div align=center>
    <table>
        <tr>
            <th width=500>Top side of the PCB</th>
            <th width=500>Bottom Side of the PCB</th>
        </tr>
        <tr align=center>
            <td>Circuit Body Fount</td>
            <td>Circuit Body Bottom</td>
        </tr>
    </table>
</div>

<div align=center>
<table>
<tr>
<th>2.5mm Connector 2/3 Pin Male/female Adapter Right Angle Pin Header White Socket</th>
<th>Actual Photo of the Circuit</th>
</tr><tr>
<td width=500 align=center>pin</td> 
<td width=500 align=center>ciruit</td> 
</tr>
</table>
</div>

# <div align="center">HOME[Return Home](../../)</div>

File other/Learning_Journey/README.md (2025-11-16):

<div align="center">logo</div>

# <div align="center">Project Development and Technical Learning Journey </div>

- The following is a development record of the self-driving car model design and task-solving, covering mechanical design and manufacturing, circuit design and implementation, electronic device selection, programming and testing, and the overall problem-solving process.

- ### Autonomous Vehicle Design: Key Upgrades and Iterations
  This autonomous vehicle design **builds upon** the rich experience inherited from the senior team (**Shinan-Fire-On-All-Cylinders**) and integrates my practical insights from last year's World Competition.

  We didn't just reference the successful elements of the previous year's winning teams; we implemented **key technological iterations**:

  * **Controller Upgrade:** The main controller has been upgraded from the standard Jetson Nano to the **superior-performing Nvidia Jetson Orin Nano**.
  * **Mechanical Overhaul:** We have **restructured and optimized** the vehicle's mechanical components, specifically the steering and chassis.
  * **Vision Enhancement:** Image processing has been **significantly enhanced** for greater efficiency and accuracy.

  The integration of all these upgrades and innovative design elements is squarely aimed at **comprehensively strengthening** the vehicle's overall performance and competitiveness.
## 2025/02/28 ~ 2025/03/07  

**Member:** HU,SIAN-YI, LIN ZHAN-RONG, ZHANG YI-WEI

**Content:**  

### **Team Experience and Model Weight Reduction Strategy** 

Our teammate, **HU,SIAN-YI**, has accumulated a profound **practical foundation** in the fields of **mechanical design** and **program control optimization**, drawing upon his years of experience participating in the "Future Engineers Competition".

<div align="center">
<table width="100%">
<tr>
<th>Team photo </th>
<th>Funny photo </th>
</tr>
<tr>
<td width="50%">team_photo
</td>
<td width="50%">team_photo
</td>
</tr>
</table>
</div>

Considering the annual changes in competition themes and rules, and having **assimilated the excellent achievements of last year's world champion team in image recognition technology**, our team conducted in-depth discussions and decided to implement a **critical weight reduction design** for this year's competition model.

By **simplifying the overall vehicle structure**, we **aim to achieve** the following key advantages and performance conditions:
* We **expect** to optimize the robot's **smoothness when entering and exiting the parking area**.
* **Significantly enhance** its **maneuverability and agility** on the field.
* **Enable** it to **avoid obstacles more precisely**.
* Thereby **comprehensively stabilize the vehicle's operational performance**. 
<div align="center">
<table>
<tr align="center">
<th>2024 World Championship Vehicle Model</th>
<th>Tentative Vehicle Model for the 2025 National Competition</th>
<th>Team Research and Data Review Process Documentation</th>
</tr>
<tr align="center">
<td width="33%">Vehicle_cad</td> 
<td width="33%">vehicle Underfloor</td> 
<td width="33%"> data</td>
</tr>
</table>
</div>

**Design Reference, Technical Findings, and Correction Strategy**
- To establish the design foundation and optimization direction for this project, we conducted the following referencing and analysis:
Design Reference Sources: We reviewed the engineering documentation from our school's past teams and conducted a deep analysis of the technical files from last year's world champion team.

- Technical Findings and Correction Strategy:

   - Image Recognition: We found that last year's world champion team executed image recognition technology in an extremely correct and highly efficient manner, marking this as an area worthy of deep study and emulation. Consequently, we established this technical direction as our primary strategy for correction and enhancement.

    - Model Size and Obstacle Avoidance: Furthermore, we observed that some teams' vehicle models were significantly smaller than ours. These smaller models demonstrated superior performance in their ability to avoid obstacles.

## 2025/03/08 ~ 2025/03/21
**Member:** HU,SIAN-YI, LIN ZHAN-RONG, ZHANG YI-WEI

**Content:**

### **System Deployment and Remote Development Environment Setup** 

This week's work focused on **system installation** and **driver downloads**.

Considering the risks associated with directly operating the **Jetson Nano** via a small screen, specifically **inconvenient interface operation** and the potential for **damage to the connection ports**, we decided to adopt a more efficient development approach: we deployed **NoMachine remote desktop software** on the Jetson Nano. This action aims to provide an **efficient and stable** remote operational environment for the subsequent tasks of **autonomous driving program writing** and **system debugging**.

**Supporting Documentation:**
Photos of the system installation, driver downloads, and remote desktop functionality test are attached below as evidence.

<div align="center">
    <table>
        <tr align=center>
            <th width=50% style="text-align: center;">Jetson  Nano Software Environment Installation</th>
            <th width=50% style="text-align: center;">Jetson  Nano Software Environment Testing</th>
        </tr>
        <tr>
            <td></td>
            <td></td>
        </tr>
    </table>
</div>

## 2025/03/22 ~ 2025/04/04

**Member:** HU,SIAN-YI, LIN ZHAN-RONG, ZHANG YI-WEI

**Content:** 

### **Second Generation Circuit Design and Initial PCB Practical Experience** 

#### **Design Motivation and Process Transition**
To **prevent potential short-circuit damage to the controllers caused by soldering on pegboards** and to achieve a **cleaner, more configurable** board layout, we decided to use **EasyEDA software to draw the Printed Circuit Board (PCB)**. Subsequently, we produced the **Second Generation circuit board** using the **chemical etching process**.

#### **Design Error and Practical Learning**
As this was the team's **first time** designing a PCB, we initially **overlooked the standard component layout templates built into the design software (EasyEDA)**. Instead, we relied on **manual measurement of the pin header pitch** as the design basis. However, due to our **limited experience**, after the second-generation board was fabricated, we discovered that the **pitch setting was too small**, ultimately preventing the electronic components from being properly inserted.

#### **Experience Summary and Subsequent Action**
Despite this setback, this failure provided **invaluable hands-on experience**. It prompted us to immediately launch the **design correction and optimization process**, and the revised design was subsequently sent to the factory for the **Third Generation Version**.

<div align="center">
    <table>
        <tr align=center>
            <th width=50% style="text-align: center;">Initial Design V1.0 (Pegboard) - Front View</th>
            <th width=50% style="text-align: center;">Initial Design V1.0 (Pegboard) - Back View</th>
        </tr>
        <tr>
            <td width=50%></td>
            <td width=50%></td>
        </tr>
    </table>
</div>

<div align="center" >
    <table >
        <tr align="center">
            <th>Second-Generation Design V2.0 (PCB) - Front View</th>
            <th>Second-Generation Design V2.0 (PCB) - Back View</th>
        </tr>
        <tr align="center">
            <td width=50%>First-Generation PCB Front View</td>
            <td width=50%>First-Generation PCB Back View</td>
        </tr>
    </table>
</div>

## 2025/04/05 ~ 2025/04/11
**Member:** HU,SIAN-YI, LIN ZHAN-RONG, ZHANG YI-WEI

**Content:** 

### **Autonomous Car Program Commencement and Communication Protocol Study**

This week, we officially initiated the **coding of the autonomous car's core program**. To ensure the **Main Control Unit (Nvidia Jetson Nano)** and the **Auxiliary Unit (Raspberry Pi Pico)** can achieve **efficient coordinated operation**, we dedicated time to deeply research key **communication protocols and technical aspects**.

The specific research areas included:
* **Main-Auxiliary Unit Communication:** Investigating the **stable communication mechanism between the Nvidia Jetson Nano and the Raspberry Pi Pico**.
* **Precise Encoder Control:** Studying how to utilize the **Raspberry Pi Pico to precisely control the DC motor's encoder**, enabling accurate speed and position management.
* **Sensor Data Acquisition:** Implementing technical steps such as **value reading and data processing** for the **ultrasonic sensor**.

 <div align=center>
    <table>
        <tr>
            <th align=center>Search for relevant materials.</th>
            <th align=center>Write a self-driving car program.</th>
        </tr>
        <tr>
            <td>Searched for relevant information online.</td>
            <td>Coding the self-driving-cars program.</td>
        </tr>
    </table>
 </div>

## 2025/04/12 ~ 2025/04/25
**Member:** HU,SIAN-YI, LIN ZHAN-RONG, ZHANG YI-WEI

**Content:** 

### **Jetson Nano System Setup and UART Communication Implementation**

This week, team member **HU,SIAN-YI** successfully completed the **operating system installation for the Nvidia Jetson Nano**, configuring all necessary hardware drivers and software packages.

#### **System Configuration Highlights:**
* **Hardware Drivers:** Successfully installed drivers for the **TP-Link T3U Plus (AC1300)** wireless adapter, the **IMX477 camera module**, and the **BNO055 gyroscope sensor**.
* **Software Environment:** Installed the **OPENCV** package for image recognition, **Cython** for performance acceleration, and software utility packages for **UART and I2C communication tools**.

#### **Program Development and Communication Implementation:**
* Building on this foundation, we have **successfully written the basic program architecture for the autonomous car**.
* Crucially, we **successfully implemented the UART (Universal Asynchronous Receiver-Transmitter) protocol**, establishing and verifying a **stable communication mechanism between the Raspberry Pi Pico and the Nvidia Jetson Nano**.
* This key achievement allows us to smoothly and reliably transmit **control commands (such as speed and steering)** generated by the **Nvidia Jetson Nano (Main Control Unit)** to the **Raspberry Pi Pico (Auxiliary Control Unit)** for low-level execution.

#### The UART Program is Shown Below

  **Nvidia Jetson Nano**
   ```python
    import serial as AC
    import struct
    combined_control_signal = 30
    turn_side = 0
    PWM = 80
    try:
        ser = AC.Serial('/dev/ttyTHS1', 115200, timeout=1)
    except AC.SerialException as e:
        print(f"Error: Could not open serial port: {e}")
        exit()
    data_to_send = (int(combined_control_signal), int(turn_side),int(PWM))
    header = b"A"
    send_data_value = struct.pack('3i', *data_to_send)
    send_data_value = header + send_data_value
    ser.write(send_data_value)
   ```
   **Raspberry Pi Pico**
   
   ```python
    from machine import UART, Pin
    import struct
    uart = UART(0, baudrate=115200, tx=Pin(16), rx=Pin(17))
    def jetson_nano_return(number):
        global data_value
        HEADER = b"A"
        HEADER_SIZE = len(HEADER)
        DATA_SIZE = 12
        TOTAL_SIZE = HEADER_SIZE + DATA_SIZE
        if uart.any():
            data = uart.read(TOTAL_SIZE)
            if len(data) == TOTAL_SIZE:
                header_index = data.find(HEADER)
                if header_index != -1:
                    start_index = header_index + HEADER_SIZE
                    data = data[start_index:] + data[:start_index]
                    data_value = struct.unpack('3i', data[:DATA_SIZE])
                    return data_value[number]
                else:
                    print("Error: Incorrect header received.")
            else:
                print("Error: Incomplete data received.")
        return data_value[number]

   ```
## 2025/04/26 ~ 2025/05/02

**Member:** HU,SIAN-YI, LIN ZHAN-RONG, ZHANG YI-WEI

**Content:**  

### PCB Layout Error Correction and UART Transmission Optimization

#### **1. PCB Layout Error and Version Correction (V3.0/V4.0)**
* **Pitch Correction:** During the development of the **Second Generation Version**, based on feedback from the prior generation, we used the design software's built-in **standard example diagrams** to recalibrate the pin header pitch, successfully correcting the original design error.
* **Polarity Reversal:** However, due to an **operational oversight**, when implementing the PCB layout, we **mistakenly treated the back view as the front design**, which resulted in a major issue of **reversed polarity** upon board fabrication.
* **Error Fix:** Fortunately, this error was discovered immediately during the assembly and testing phase. We promptly corrected the layout orientation in the **subsequent version** and **comprehensively reviewed the alignment specifications of all layers** to ensure the design file and the final physical product were **completely consistent**.

#### **2. UART Transmission Issue and Ongoing Optimization**
While testing **UART data transmission**, we discovered **instances of data loss (dropping data)**. To ensure the reliability of control command transmission, we are **continuously developing and debugging the code**, focusing on correcting this error to **enhance communication stability**.

<div align="center" >
    <table>
        <tr>
            <th>Third-Generation Design V3.0 (PCB) - Front View</th>
            <th>Third-Generation Design V3.0 (PCB) - Back View</th>
        </tr>
        <tr align="center">
            <td>
                data
            </td>
            <td>
                data
            </td>
        </tr>
    </table>
</div>

## 2025/05/03 ~ 2025/05/09
**Member:** HU,SIAN-YI, LIN ZHAN-RONG, ZHANG YI-WEI

**Content:**

### **Open Challenge Strategy and Optimization of Obstacle Challenge Strategy**

### 1. Open Challenge Strategy

Given that the rules for the **Open Challenge rounds** remain **consistent** with previous years, we have decided to implement the solution developed last year and use it for preliminary vehicle performance testing.

### 2. Program Modification and Optimization for the Obstacle Challenge

Considering that this year's rules for the **Obstacle Challenge rounds** include the new task of starting from the **parking lot** and executing **parallel parking** into the designated area, we were required to modify and **thoroughly optimize** our previous year's **Self-Driving Car** obstacle avoidance program.

### 3. Implemented Obstacle Avoidance Strategy and Logic

Our implemented obstacle avoidance strategy and logic are as follows:

* **Establishment of Path Reference:** We draw **two path lines** with a specific slope on the video screen to serve as the reference direction for the vehicle's travel.
* **Calculation of Target Center Coordinates:** The system utilizes a subroutine within the file `detect_color_final.py` to calculate the **center coordinates** of the **target object** on the screen.
* **Calculation and Execution of Steering Angle:** The **Vehicle** subsequently calculates the necessary **turning angle** based on the coordinate difference between the **object center coordinates** and the **path lines**, thus executing **precise** obstacle avoidance maneuvers

- The image below displays the autonomous car's actual operational screen during mission execution.
 <div align=center>
    <table>
        <tr>
            <th colspan=3 >Screenshot of the Image Feed During Jetson Nano Program Execution - Jetson Nano </th>
        </tr>
        <tr>
            <td></td>
            <td></td>
            <td></td>
        </tr>
    </table>
 </div>

## 2025/05/10 ~ 2025/05/16
**Member:** HU,SIAN-YI, LIN ZHAN-RONG, ZHANG YI-WEI

**Content:**

### **Obstacle Challenge Program Optimization and Compound Steering Logic**

#### **1. Steering Mode and Lap Counting Mechanism**
This week, we continued optimizing the Obstacle Challenge program by adding a **detection mechanism for the start and end of steering**. This mechanism is used to **determine if the vehicle is still within the turning zone**, facilitating the **accurate counting of completed laps** around the field.

* **Mode Switching:** When the image screen **detects the specific lines marking the turning zone**, the system automatically switches to the **"Steering Mode"**.
* **Exit Turning Zone Logic:** The program requires the simultaneous satisfaction of **three conditions** to confirm the vehicle has left the turning zone and increment the steering count:
    * **Heading Angle Change**
    * **HSV Color Recognition**
    * **Time Condition**

#### **2. Compound Obstacle Avoidance Optimization During Steering**
* Following practical testing, we found that the original steering logic occasionally led to the vehicle **colliding with the obstacle blocks**.
* To resolve this issue, we **added a compound obstacle detection logic** within the steering mechanism:
    1.  When the autonomous car **identifies an obstacle block during the turning process**, it **prioritizes obstacle avoidance**.
    2.  If it detects the vehicle body is **approaching a wall**, it **prioritizes moving away from the wall**.
    3.  **Finally**, it determines whether the vehicle has exited the turning zone.

**The logic code for determining the exit from the turning zone is shown below.**

```python
if elapsed_time >= 0.7 and color_y_positions[0] ==0 and color_y_positions[1] == 0 and
    heading < target_heading[count+1] + 35 and heading > target_heading[count+1] - 35:
    turn_side = 2
    if count >= 3:
        count = 0
        round_number +=1
        if round_number == 2:
            turn_side = 3
            time_count = 0
            start_time = time.time()
    else:
        count += 1
        combined_control_signal = 0
```

## 2025/05/17 ~ 2025/05/23
**Member:** HU,SIAN-YI, LIN ZHAN-RONG, ZHANG YI-WEI

**Content:** 

### **Program Auto-Startup Mechanism and Raspberry Pi Pico Signal Detection**

#### **Need and Implementation of Auto-Startup Mechanism**
To address the efficiency issue of manually starting the main program before every operation, we designed and implemented an **automated startup mechanism** on the **Jetson Nano**.

* **Service Script Writing:** We authored a **startup script (`open-mode.sh`)** and configured it using the **Linux Systemctl service (`open-mode.service`)**, enabling the system to **automatically execute this script upon every boot**.
* **Startup Signal Detection:** After execution, the startup script (running `open-mode.py`) continuously **monitors the Raspberry Pi Pico via the UART protocol for a specific "Program Start" signal**. Once a valid signal is received, the main control loop of the autonomous car commences execution.

The code for `open-mode.service`, `open-mode.sh`, and `open-mode.py` is provided below.

* **open-mode.service Code**
 ```bash
[Unit]
Description=Open Terminal with Python Script on Boot
After=graphical.target network.target
Wants=graphical.target

[Service]
Type=simple
User=user
Environment="DISPLAY=:0"
Environment="XAUTHORITY=/home/user/.Xauthority"
Environment="DBUS_SESSION_BUS_ADDRESS=unix:path=/run/user/1000/bus"
WorkingDirectory=/home/user/code
ExecStart=/bin/bash -c "/home/user/code/open-mode.sh"
Restart=on-failure
RestartSec=5s

[Install]
WantedBy=default.target
 ```

* **open-mode.sh Code**
 ```bash
#!/bin/bash
while [ ! -e /tmp/.X11-unix/X0 ]; do
    sleep 1
done
until xhost >/dev/null 2>&1; do
    sleep 1
done
export DISPLAY=:0
export XAUTHORITY=/home/user/.Xauthority
export DBUS_SESSION_BUS_ADDRESS=unix:path=/run/user/1000/bus

/usr/bin/gnome-terminal --title='start code' -- bash -c '/home/user/code/open-mode.py; exec bash'
 ```

* **open-mode.py Code**
 ```python
#!/usr/bin/python3
import Jetson.GPIO as GPIO
import time
import subprocess
import os

GPIO.setmode(GPIO.BOARD) 
input_pin = 7
output_pin = 40
GPIO.setup(output_pin, GPIO.OUT)
GPIO.setup(input_pin, GPIO.IN)

process = None
GPIO.output(output_pin, GPIO.LOW)
try:
    command = "xrandr --fb 1900x1240"
    subprocess.run(command, shell=True)
    GPIO.output(output_pin, GPIO.LOW)
    while True:
 
        if GPIO.input(input_pin) == GPIO.HIGH:
            print("A high level was detected, so another program was executed.")        
            if process is not None and process.poll() is None: 
                time.sleep(1)  
                continue
            command = "echo '0000' | sudo -S chmod 777 /dev/ttyTHS1"
            subprocess.run(command, shell=True)
            folder_path = "/home/user/code/"  
            os.chdir(folder_path)          
            
            process = subprocess.Popen(
                ["xterm", "-e", "/usr/bin/python3", "/home/user/code/jetson_nano_main_final.py"]
            ) 

        else:
            if process is not None and process.poll() is None: 
                print("Terminate the previously running program.")
                process.terminate()  
                process.wait()      
            GPIO.output(output_pin, GPIO.LOW)
            print("LOW，Turn Light")

        time.sleep(1)

except KeyboardInterrupt:
    GPIO.cleanup()
 ```

## 2025/05/24 ~ 2025/05/30
**Member:** HU,SIAN-YI, LIN ZHAN-RONG, ZHANG YI-WEI

**Content:**

### **Obstacle Challenge Parking Procedure Design and Strategy**

This week, our focus is dedicated to finalizing the **parking procedure programming for the Obstacle Challenge rounds**.

* **Parking Strategy:** We adopted the method of **Perpendicular Reverse Parking** (or **Right-Angle Back-in Parking**) as our primary strategy, ensuring the vehicle can **precisely and efficiently enter the designated parking area**.
* **Flow Description:** The image below illustrates the **detailed execution flow diagram for the parking procedure**.

 <div align=center>
    <table>
        <tr>
            <th>2025 National Competition: Parallel Reverse Parking Procedure Diagram </th>
        </tr>
        <tr>
            <td></td>
        </tr>
    </table>
 </div>

## 2025/05/31 ~ 2025/06/06
**Member:** HU,SIAN-YI, LIN ZHAN-RONG, ZHANG YI-WEI

**Content:** 

### **Parking Procedure Stability Optimization and Ultrasonic Sensor Integration** 

* After repeated testing, we found that the autonomous car's **parking parameter tuning process was overly cumbersome**. The main reason was that the **tolerance range set in the program was too small**, often causing the vehicle to **collide with the parking zone walls** during execution.
* To resolve this issue, we **activated the ultrasonic sensor mounting holes previously reserved on the chassis** and **utilized the ultrasonic sensor readings to assist** the autonomous car in completing the parking maneuver.
* This design **significantly enhanced the stability and success rate of the parking procedure**, effectively addressing the low tolerance problem.

The code for reading the ultrasonic sensor values is shown below.

 ```python
def measure_distance(trig, echo):
    # Send trigger pulse
    trig.value(0)
    time.sleep_us(2)
    trig.value(1)
    time.sleep_us(10)
    trig.value(0)

    # Read Echo pulse width
    duration = time_pulse_us(echo, 1)

    # Calculate distance (speed of sound is approximately 343 m/s)
    distance = (duration / 2) * 0.0343

    return distance
 ```

## 2025/06/07 ~ 2025/06/20
**Member:** HU,SIAN-YI, LIN ZHAN-RONG, ZHANG YI-WEI

**Content:**

### **Parking Optimization Results and Parking Zone Exit Procedure Development**

#### **1. Parking Feature Optimization Results**
With the **integration of the ultrasonic sensor-assisted parking function** last week, the number of required **parameter adjustments during parking significantly decreased**, validating the effectiveness of the new design.

#### **2. Parking Zone Exit Procedure Development**
This week, we began coding the **"Parking Zone Exit Procedure"** for the **Obstacle Challenge rounds**. The key design aspects of this procedure are:
* **Control Unit:** The exit procedure is controlled by the **Jetson Nano main controller**.
* **Direction Determination Logic:** The system determines the required **clockwise or counterclockwise travel direction** at the start of the competition by **detecting the Region of Interest (ROI) values on the left and right sides of the image frame**.
* **Mode Switching:** Once the autonomous car **successfully exits the parking zone**, the system automatically switches the mode to **"Obstacle Avoidance Mode"** and continues to proceed based on the avoidance logic.

The **autonomous car's exit procedure code** is shown below.

 ```python
if turn_side == 8:
    PWM = -45
    if  roi_values[0]> roi_values[1] and start_0:
        ROI_0 = True
        start_1 = True
        start_0 = False
    elif  roi_values[0]< roi_values[1]and start_0:
        ROI_1 = True
        start_1 = True
        start_0 = False
    if  abs(heading) < 60 and start_1 or abs(heading) > 80 and start_1:
        if ROI_1:
            combined_control_signal = 180
        elif ROI_0:
            combined_control_signal = -180
    if abs(heading) > 60 and abs(heading) < 80 and start_1:
        start_2 = True
        start_1 = False
    if start_2:
        PWM = 40
        combined_control_signal = 0
    if start_2 and roi_values[2] > 4000:
        start_2 = False
        start_3 = True
    if abs(heading) > 10 and abs(heading) < 170 and start_3:
        if ROI_1:
            combined_control_signal = -180
        elif ROI_0:
            combined_control_signal = 180
    if abs(heading) < 10 and start_3  or abs(heading) > 170 and start_3:
        start_2 = False
        start_1 = False
        turn_side = 0
 ```

## 2025/06/21 ~ 2025/06/27
**Member:** HU,SIAN-YI, LIN ZHAN-RONG, ZHANG YI-WEI

**Content:**

### **Steering Angle Limitation and Mechanism Protection**

The **servo motor-driven front-wheel steering mechanism** of the autonomous car has **limited rotation angle capacity**. If the rotation angle is set **too wide**, it could potentially lead to the **steering structure being twisted and broken**, or cause the **servo motor to burn out**.

Therefore, to **prevent damage to the servo motor-driven front-wheel steering mechanism or the steering structure from being twisted**, we **added a strict angle limitation** at the end of the code's control logic, ensuring that steering maneuvers always remain within the safe operating range of the mechanism.

The code for **limiting the steering angle** is shown below.

 ```python
if combined_control_signal > 180:
    combined_control_signal=160
if combined_control_signal < -180:
    combined_control_signal=-160
 ```

## 2025/06/28 ~ 2025/07/04 
**Member:** HU,SIAN-YI, LIN ZHAN-RONG, ZHANG YI-WEI

**Content:** 

### **Main Circuit Board Fourth Generation Functional Test Results** 

Following the successful correction of design issues found in the previous two versions (V2.0 and V3.0), the **Main Circuit Board's Fourth Generation Version (V4.0) has successfully passed functional testing**. The results from actual operational tests indicate that there are **no anomalies in the pin header connections or the circuit layout**, and the **system operates stably**.

Notably, due to its stable performance, the V4.0 version **became the primary circuit board used during the National Competition**.

<div align="center" >
    <table >
        <tr align="center">
            <th>Fourth-Generation Design V4.0 (PCB) - Front View</th>
            <th>Fourth-Generation Design V4.0 (PCB) - Back View</th>
        </tr>
        <tr align="center">
            <td>data</td>
            <td>data</td>
        </tr>
    </table>
</div>

## 2025/07/05 ~ 2025/07/11
**Member:** HU,SIAN-YI, LIN ZHAN-RONG, ZHANG YI-WEI

**Content:** 

### **Chassis Friction Correction and Steering Smoothness Optimization** 

While testing the obstacle avoidance program, we observed that the autonomous car experienced **slight stuttering during cornering**. Inspection revealed the problem originated from the **chassis structure**: as the **steering knuckle was in direct contact with the chassis**, the resulting **excessive friction** caused the drivetrain to **jam**.

To resolve this issue, we implemented the following chassis optimization:
* **Enlarged the holes originally used to fix the steering knuckle**.
* **Switched to placing bearings** within the enlarged holes to **reduce friction**.

Following testing, the **new chassis structure incorporating bearings effectively improved steering smoothness**, allowing the autonomous car to navigate corners **more smoothly**.

 <div align=center>
    <table>
        <tr>
            <th colspan=2>Before and After Modification</th>
        </tr>
        <tr>
            <td></td>
            <td></td>
        </tr>
    </table>
 </div>

## 2025/07/12 ~ 2025/08/22
**Member:** HU,SIAN-YI, LIN ZHAN-RONG, ZHANG YI-WEI

**Content:** 

* Below are the **3D View**, **Schematic Diagram**, and **PCB Layout** of the **currently corrected and finalized circuit board**.
* **Program and Functional Testing for the Obstacle Challenge**
    we will **continue to focus on executing the program and functional testing** for the **Obstacle Challenge rounds** to ensure optimal vehicle performance in complex environments (e.g., red pillars, green pillars , and parallel parking).
* **Continuous Documentation and Organization of Engineering Files on GitHub Repository**
    As part of the engineering design and development process, teams must **continuously** document and upload information such as engineering progress, final vehicle design, and final vehicle source code to a **GitHub public repository**.

  <div align=center>
    <table>
    <tr>
    <th>3D view</th>
    <th>Circuit schematic</th>
    <th>PCB layout drawing</th>
       </tr>
       <tr>
    <td align=center ></td>
    <td align=center ></td>
    <td align=center ></td>
       </tr>
    </table>
  </div>

## 2025/08/23 ~ 2025/08/29
**Member:** HU,SIAN-YI, LIN ZHAN-RONG, ZHANG YI-WEI

**Content:** 

### **National Competition Journey, Challenges, and Qualification** 🏆

Our National Competition took place on **August 23rd**. Despite a challenging process, we successfully qualified.

#### **Morning Qualifying Rounds**
* **First Attempt:** The round ended prematurely as the vehicle **collided with the inner side wall**.
* **Second Attempt:** We successfully **completed the three-lap circuit task**, but during the **final parking maneuver**, the autonomous car **exceeded the designated parking zone**, preventing us from earning full points.
* **Result:** Even without achieving a perfect score, our strong performance allowed us to **successfully advance to the afternoon final rounds**.

#### **Afternoon Final Rounds (Obstacle Challenge)**
* **Final Challenges:** In the afternoon finals, we **still failed to achieve a perfect solution**.
    * **Obstacle Avoidance:** In the first round, the autonomous car **moved an obstacle block**, resulting in an incomplete score for the obstacle avoidance task.
    * **Parking Issue:** During the final parking sequence, the vehicle **left the parking/starting zone after passing the final obstacle**, thus failing to complete the parking task.

#### **Final Achievement and Outlook**
Despite a **difficult and challenging competition process**, we successfully secured the **first-place ranking**, earning the qualification to **represent Taiwan in the WRO Future Engineers World Final**. We plan to **fully absorb the practical experience and lessons learned from this National Competition** and aim to participate in the World Final **in better condition**, striving to achieve **outstanding results and bring honor back home**.

### **Engineering Documentation Internationalization and Continuous Update Strategy**

-  Documentation Internationalization and Continuous GitHub Updates

    To **comply with the regulations** for **advancing to the international competition**, we must **strictly adhere** to the documentation requirements stipulated by the competition rules, which mandates that all technical documentation be provided **in English**.

    Therefore, we will implement the following actions:

    1.  **Documentation Translation:** The **existing** Chinese engineering documentation on the GitHub repository will be **fully translated** into an **English** version.
    2.  **Continuous Update and Synchronization:** Going forward, **all new and revised** engineering documentation will be **recorded directly in English** and **continuously synchronized and updated** to the **GitHub repository** to ensure the **timeliness** and **consistency** of the information.

 <div align=center>
    <table>
        <tr>
            <th>Awaiting Testing</th>
            <th>Competition Action Photo</th>
            <th>Award Ceremony Photo</th>
        </tr>
        <tr>
            <td></td>
            <td></td>
            <td></td>
        </tr>
    </table>
 </div>

## 2025/08/30 ~ 2025/09/05
**Member:** HU,SIAN-YI, LIN ZHAN-RONG, ZHANG YI-WEI

**Content:**

### **Main Controller Upgrade to Jetson Orin Nano and Communication Optimization** 

#### **1. Main Controller Upgrade Decision and Rationale**
During our participation in the National Competition, we identified that the **Jetson Nano lacked sufficient computational performance** to handle the complexity of the required competition programs. Concurrently, considering that the **more efficient Nvidia Jetson Orin Nano controller had seen a price reduction**, and the **Nvidia Jetson Nano is now discontinued**—making the procurement of backup controllers challenging—we decided to upgrade the main controller to the **significantly more computationally efficient Jetson Orin Nano**.

#### **2. Communication Protocol and Auxiliary Controller Swap**
Following the main controller upgrade, we began investigating the use of the **WebSockets protocol** to establish **communication between the Jetson Orin Nano and the Raspberry Pi Pico**. As WebSockets communication necessitates **stable network connectivity for both ends**, we replaced the original Raspberry Pi Pico with the **WiFi-enabled Raspberry Pi Pico W**, meeting the requirement for wireless communication and setting the foundation for the future system architecture.

<div align=center>
    <table>
       <tr>
           <th width=50%>2025 National Competition Vehicle Model
           <th width=50%>2025 National Competition Model: Latest Version Under Ongoing Optimization
       </tr>
       <tr>
           <td align=center></td>
           <td align=center></td>
       </tr>
       <tr>
           <th>Second Generation Steering Structure (V2.0) </th>
           <th>Third Generation Steering Structure (V3.0) </th>
       </tr>
       <tr>
           <td align=center></td>
           <td align=center></td>
       </tr>
       <tr>
           <th colspan=2>Onshape 3D Model Structure Sketch</th>
       </tr>
       <tr>
           <td align=center></td>
           <td align=center></td>
       </tr>
       <tr>
           <th>Raspberry Pi Pico</th>
           <th>Raspberry Pi Pico W</th>
       </tr>
       <tr>
           <td align=center></td>
           <td align=center></td>
       </tr>
    </table>
</div>

## 2025/09/06 ~ 2025/09/12
**Member:** HU,SIAN-YI, LIN ZHAN-RONG, ZHANG YI-WEI

**Content:**

### **Steering Optimization, Complex Parking Flow, and Assembly Experience**

#### **1. Correction of Third-Generation Steering Torque Issue**
After identifying a **torque structure problem** in the third-generation steering mechanism, we implemented a critical correction:
* **Component Replacement:** We **deprecated the original spherical cross joint component**.
* **Optimization Goal:** The **rounded end was moved to the linkage rod**, ensuring that when the **steering angle is 0 degrees**, the **steering rack and the linkage rod are precisely aligned at 90 degrees**, thus optimizing mechanical transmission efficiency.

#### **2. New Complexified Parking Procedure Flow**
* **Procedure Refinement:** We began **rewriting a new autonomous car parking procedure flow**.
* **Design Objective:** The new parking flow is designed to be **more complex than the procedure used in the National Competition**, anticipating stricter requirements in the World Final.

A comparison diagram of the two procedures is shown below.

#### **3. Experience Sharing on 3D Printed Parts Assembly**
* **Assembly Challenge:** We faced **significant difficulties** when **installing the spherical joint section of the steering structure** because the parts had already **undergone UV curing**.
* **Solution and Process:** Our solution involved the following steps:
    1.  Prior to **UV curing**, we first **finely sanded the parts with sandpaper**.
    2.  The parts were then **assembled** and placed into the **UV curing machine as an assembled unit**.
    3.  After curing was complete, **oil was applied to the connection points of the movable components**.
* **Result:** This sequence of steps **successfully resolved issues related to difficult assembly and rough rotation**.

 <div align=center>
    <table>
        <tr>
            <th>Fourth Generation Steering Structure (V4.0) </th>
            <th>Photo of Teammate Coding the Forward Parking Program</th></th>
        </tr>
        <tr>
            <td></td>
            <td></td>
        </tr>
    </table>
 </div>

 <div align=center>
    <table>
        <tr>
            <th>2025 National Competition: Parallel Reverse Parking Procedure Diagram</th>
            <th>2025 WRO World Final: Diagram of the Parallel Reverse Parking Procedure</th>
        </tr>
        <tr align=center>
            <td></td>
            <td></td>
        </tr>
    </table>
 </div>

 <div align=center>
    <table>
        <tr>
            <th>Fine Sanding the Ball Joints of the Steering Mechanism</th>
            <th>Assembly of the Steering Mechanism</th>
        </tr>
        <tr>
            <td></td>
            <td></td>
        </tr>
        <tr>
            <th>Ultraviolet (UV) Post-Curing of 3D Printed Parts</th>
            <th>Applying Silicone Oil to the Ball Joints</th>
        </tr>
        <tr>
            <td></td>
            <td></td>
        </tr>
    </table>
 </div>

## 2025/09/13 ~ 2025/09/19
**Member:** HU,SIAN-YI, LIN ZHAN-RONG, ZHANG YI-WEI

**Content:**

### **Jetson Nano System Downgrade and Dedicated Workstation Setup** 

As the **newly purchased Nvidia Jetson Nano** was equipped with the **latest operating system version (JetPack 6.2.1)**, testing revealed that it **did not support** the **IMX477 camera module**, a crucial piece of equipment for our competition.

To resolve this critical issue, we decided to **downgrade the operating system to JetPack version 5.1.2**, which ensures that the camera module is supported and fully operational.

During this process, we learned the procedures for **upgrading and downgrading the JetPack system** from our instructor. However, since the **Nvidia SDK Manager** requires a **physical Ubuntu host machine** to function correctly, our instructor specially **set up an Ubuntu system host machine** at the back of the club room, dedicated solely to operating the SDK Manager.

The procedure for using the SDK Manager to perform JetPack upgrades and downgrades is as follows.

 <div align=center>
    <table>
        <tr>
            <th colspan=2>Learning the Operational Procedures for JetPack Operating System Upgrades and Downgrades </th>
        </tr>
        <tr>
            <td width = "50%"></td>
            <td width = "50%"></td>
        </tr>
    </table>
 </div>

- ### Installation Commands 

 ```bash
wget https://developer.download.nvidia.com/compute/cuda
/repos/ubuntu2204/x86_64/cuda-keyring_1.1-1_all.deb
sudo dpkg -i cuda-keyring_1.1-1_all.deb
sudo apt-get update
sudo apt-get -y install sdkmanager
 ```

  - ### NVIDIA SDK Manager: Operational Procedure for JetPack OS Upgrades and Downgrades
<div align=center>
<table>
<tr>
<th>Connect Host - Connect the Jetson Orin Nano controller to the Ubuntu host machine via a USB cable..</th>
<th>Confirm Connection - Verify that the Jetson Orin Nano is successfully connected and recognized by the SDK Manager.</th>
<th>Select Dev Kit - Select the target Developer Kit in the interface.</th>
</tr>
<tr>
<td></td>
<td></td>
<td></td>
</tr>
<tr>
<th>Choose Version - Select the desired JetPack version from the menu for installation or downgrade.</th>
<th>Check Options - Check the required software components on the left side (such as OS, SDKs), and click "Next".</th>
<th>Enter Password - Enter the administrator password as prompted.</th>
</tr>
<tr>
<td></td>
<td></td>
<td></td>
</tr>
<tr>
<th>Fill Info - Fill in the relevant information for the target board.</th>
<th>Finish Install - After installation is complete, click "Finish" to exit.</th>
<th>System Interface - The Jetson Orin Nano system interface after installation is complete (Result presentation).</th>
</tr>
<tr>
<td></td>
<td></td>
<td></td>
</tr>
</table>
</div>

## 2025/09/20 ~ 2025/09/26
**Member:** HU,SIAN-YI, LIN ZHAN-RONG, ZHANG YI-WEI

**Content:**

### **V5.0 PCB Design Motivation and 3D Printing Precision Correction** 

#### **1. Fifth Generation PCB Design Requirement and Motivation**
Because we replaced the original I/O controller, the **Raspberry Pi Pico, with the Raspberry Pi Pico W**, we encountered an issue with **unavailable pins** when attempting to **switch the ultrasonic sensors to infrared sensors**. Furthermore, we needed to **add plug-in terminal blocks** to the circuit board for connecting the **power supply lines for the Jetson Orin Nano**. Consequently, we initiated the design process for the **Fifth Generation PCB**.

#### **2. Steering Knuckle Toe-in Issue: The Impact of 8K vs. 14K Print Precision**
This week, we discovered that the assembled **steering knuckles** exhibited a **toe-in** problem. This issue was related to the upgrade in 3D printer precision:
* **Older Prints:** Our first and second-generation steering structures were printed using a **Stereolithography (SLA) 3D Printer 8K**.
* **New Print and Issue:** The third and fourth-generation steering structures were upgraded to use a **Stereolithography (SLA) 3D Printer 14K**. However, the 14K printer, due to its precision characteristics, printed the component's angles **larger than the original design angle** in specific areas. This resulted in the vehicle's two front wheels exhibiting a **toe-in** issue after the steering structure was assembled.
* **Solution:** We made **further modifications to the steering knuckle design** to ensure the vehicle's two front wheels are **parallel**, thereby resolving the steering difficulty.

 <div align=center>
    <table>
        <tr>
            <th colspan=2>Design Evolution of the Fifth GenerationPCB (V5.0)</th>
        </tr>
        <tr>
            <td></td>
            <td></td>
        </tr>
        <tr>
            <th>Circuit schematic</th>
            <th>PCB layout drawing</th>
        </tr>
        <tr>
            <td></td>
            <td></td>
        </tr>
        <tr>
        <th>Overhead view of the main circuit board	</th>
         <th>Bottom View of the Main Circuit Board</th>
        </tr>
        <tr>
            <td align=center width="25%" ></td>
            <td align=center width="25%"></td>
        <tr>
        <th  colspan = 2>Comparison of Physical Print Results Between SLA 3D Printers at 8K and 14K Resolutions</th>
        </tr>
        <tr>
            <th> Stereolithography (SLA) 3D Printer 8K</th>
            <th> Stereolithography (SLA) 3D Printer 14K</th>
        </tr>
        <tr>
            <td align=center></td>
            <td align=center></td>
        </tr>
        <tr>
            <th colspan=2>The Steering Structure Exhibits a Toe-in Phenomenon(This condition is visible as the two front wheels noticeably converge inwards)</th>
        </tr>
        <tr>
            <td colspan=2 align=center></td>
        </tr>
    </table>
 </div>

 ## 2025/09/27 ~ 2025/10/03
 **Member:** HU,SIAN-YI, LIN ZHAN-RONG, ZHANG YI-WEI

 **Content:**

### **Parking Positioning Sensor Optimization and BNO055 Power Correction**

#### **1. Hardware Adjustment for Parking Positioning Sensors**
* **Ultrasonic Sensor Repositioning:** Initially, our autonomous car's ultrasonic sensors were mounted on the **mid-rear sides of the vehicle body**, making it easy for the **entire vehicle body to leave the starting zone** without detecting the parking block. We therefore designed **new wooden plates and brackets** to mount the ultrasonic sensors on the **front sides of the autonomous car**.
* **Infrared Sensor Integration:** Since relying solely on ultrasonic sensors **could not achieve precise positioning for parking**, we decided to **add infrared sensors**, installing them on the **front and rear** of the car to **detect side walls and parking lot walls**. Consequently, we **redesigned the new vehicle chassis plate and L-shaped infrared brackets**.

#### **2. Electronic Correction of BNO055 Gyroscope Sensor Anomaly**
Upon receiving the new PCB (V5.0), testing revealed an intermittent issue where the **BNO055 gyroscope sensor** would return an angle reading of **zero**.
* **Root Cause:** This anomaly occurred because the sensor's VCC/GND was supplied by the **Raspberry Pi Pico W**, while its signal lines were connected to the **Jetson Orin Nano main controller**. This configuration, where the **power and signal sources were on different circuits (i.e., lacking a common ground reference)**, caused the sensor to **malfunction**.
* **Correction:** We revised the design to ensure that **both the power and signal sources for the BNO055 gyroscope sensor are uniformly supplied by the Jetson Orin Nano controller**, thereby **establishing a stable electrical potential reference**.

 <div align=center>
    <table>
        <tr>
            <th>Central Wooden Layer with Added Mounting Holes for the Ultrasonic Sensor Bracket.</th>
            <th>Additionally, the Central Wooden Layer After Modification to Include Infrared Sensor Bracket Mounting Holes.</th>
            <th>Synchronizing and Optimizing the Top Wooden Layer Based on the Revised Specifications of the Central Plate.</th>
        </tr>
        <tr>
            <td></td>
            <td></td>
            <td></td>
        </tr>
    </table>
 </div>

 <div align=center>
    <table>
        <tr>
            <th>Ultrasonic Sensor stent</th>
            <th>Infrared Sensor bracket</th>
        </tr>
        <tr>
            <td></td>
            <td></td>
        </tr>
    </table>
 </div>

 <div align=center>
    <table width=100%>
        <tr>
            <th colspan=2>Photo of the Actual Installation Location of the Ultrasonic Sensor.</th>
        </tr>
        <tr>
            <td colspan=2>Untrasonic Car</td>
        </tr>
        <tr>
            <th colspan=2>Photo of the Final Actual Installation Location of the Infrared Sensor.</th>
        </tr>
        <tr align=center>
            <td width=50% ></td>
            <td width=50% ></td>
        </tr>
    </table>
 </div>

 <div align=center>
    <table>
         <tr>
        <th colspan = 2 >Final Version(PCB)</th>
        </tr>
        <tr>
            <th>Circuit Schematic</th>
            <th>PBC Layout Drawing</th>
        </tr>
        <tr>
            <td align=center ></td>
            <td align=center ></td>
        </tr>
        <tr>
            <th>Overhead view of the main circuit board</th>
            <th>Bottom View of the Main Circuit Board</th>
        </tr>
        <tr align=center>
            <td></td>
            <td></td>
        </tr>
    </table>
 </div>

 ## 2025/10/04 ~ 2025/10/10
 **Member:** HU,SIAN-YI, LIN ZHAN-RONG, ZHANG YI-WEI

 **Content:**

### **Post-National Competition Model Optimization and System Stability Enhancement** 

#### **1. Mechanism and Sensor Protection Optimization**
* **Shortening Wheelbase and Steering Correction:** While coding the exit procedure, we noticed the car was prone to colliding with parking blocks. We initially attempted to **modify the robot's overall wheelbase** by **removing empty space on the base plate to shorten the wheel distance**. Although the issue was mitigated, the tolerance remained too small. Thus, we further modified the **limit block of the steering linkage**, **reducing its size** to give the steering mechanism **more rotation space**.
* **Infrared Sensor Protection:** During testing, we found that if the autonomous car malfunctioned and **collided with a wall or block, the infrared sensors were usually the first to be damaged**. To protect them, we **shortened the front infrared mounting block** and **extended the base plate by 19 mm**, preventing the infrared sensors from sustaining impact damage due to erroneous judgment.

#### **2. Communication Hardware Replacement and Optimization**
* **Network Receiver Swap:** Since the autonomous car uses **WebSocket for data transmission**, the network antenna is critical. However, the original **TP-Link AC1300 receiver was about 18 CM long**, making it bulky. We found an alternative, the **ASUS AC1200 receiver**, which is only $2 \text{CM} \times 1.5 \text{CM}$ in size, and **replaced the original receiver with the ASUS AC1200**.

#### **3. Customized Camera Bracket Design**
* **Design Requirement:** The original camera bracket was **assembled using LEGO parts**, making it prone to accidental disassembly.
* **Custom Implementation:** We used **Onshape to design a custom camera bracket module**, consisting of two components: the **lens mounting plate** and the **main bracket body**.
* **Functional Enhancement:** To allow for future adjustments to the camera's viewing angle, we designed **angle-adjustable sliding rails** into the bracket module.

#### **4. Jetson Orin Nano Network AP Mode Setup**
* **Issue Discovered:** During testing, we realized the **Jetson Orin Nano's network had not been set to AP (Access Point) mode**; we were instead using a mobile phone as the network transmission medium.
* **AP Mode Setup:** By searching online, we successfully found the commands to enable the **Jetson Orin Nano's AP mode** and configured it for **automatic startup**.

The commands for manual setup and using the auto-script are provided below.

 <div align=center>
    <table>
        <tr>
            <th>The Optimized and Revised Vehicle Bottom Wooden Layer.</th>
            <th>The Revised Vehicle Mid-Layer Wooden Plate.</th>
        </tr>
        <tr>
            <td align=center></td>
            <td align=center></td>
        </tr>
    </table>
 </div>

 <div align=center>
    <table>
        <tr>
            <th>Lens Mount with Integrated Light Shielding Functionality.</th>
            <th>Lens Module Fine-Tuning Mechanism.</th>
        </tr>
        <tr>
            <td align=center></td>
            <td align=center></td>
        </tr>
    </table>
 </div>

 <div align=center>
    <table>
        <tr>
            <th>TP-Link AC1300 Wi-Fi Wireless Adapter</th>
            <th>ASUS AC1200  Wi-F  Wireless Adapter</th>
        </tr>
        <tr>
            <td align=center ></td>
            <td align=center ></td>
        </tr>
    </table>
 </div>

 - #### Setting Up Access Point (AP) Mode: Manual Command Operation.

    ```bash
    sudo nmcli dev wifi hotspot ifname wlan0
     ssid "snjh_jetson" password "1234567890" 

    sudo nmcli connection modify Hotspot connection.autoconnect yes
    sudo systemctl enable NetworkManager.service
    sudo systemctl status NetworkManager

    ```

 - #### Setting Up Access Point (AP) Mode: Using Automated Script Execution[Set_AP.sh](../../src/System_Platform_Software/code/Set_AP.sh)

    ```bash
    sudo bash ./Set_AP.sh 
    ```

 ## 2025/10/11 ~ 2025/10/17
 **Member:** HU,SIAN-YI, LIN ZHAN-RONG, ZHANG YI-WEI

 **Content:**

### **System Stability, Startup Mechanism, and Hardware Optimization** 

#### **1. Image Recognition Stability Correction**
* **Root Cause:** While conducting **LAB value tuning**, we found that although the values were normal during the adjustment phase, the program **failed to accurately identify objects** during actual operation. Testing confirmed the issue stemmed from **environmental light interference** and **overly strict value tolerances**.
* **Solution:** We implemented two corrective measures:
    1.  **Adding a light shield (hood) above the lens mount**.
    2.  **Allowing a larger margin of error** after tuning the LAB values for a specific object.

#### **2. WebSockets Blocking Issue and Isolated Startup Circuit**
* **Communication Blockage:** During testing, we found that **WebSockets would block all previous actions until a connection was successfully established**, executing them simultaneously afterward. This caused anomalies upon program startup, such as the **robot moving forward while the servo motor was inactive, or the chassis being unresponsive**.
* **Startup Control Transfer:** To resolve this, we decided to assign **program startup control to the Jetson Orin Nano**.
* **Circuit Correction:** We needed to modify the program start button circuit. During this change, we encountered a problem where the **button's pressed state was not updating**. Consulting online resources revealed the necessity of connecting the circuit using a **pull-up resistor**.
* **Isolated PCB Design:** Consequently, we used **EasyEDA to custom-design a separate circuit board** dedicated solely to the **program startup button circuit**.

#### **3. Lens Mount Structure Optimization**
* **Adding Light Shield:** Since a light shield was required, we **added LEGO pinholes** to the lens mount for mounting a **LEGO $5 \times 11$ Technic panel**.
* **Adding Screw Holes:** Later, because we designed the **second independent button/LED circuit board**, we designed **screw holes** above the lens mount for installing this secondary board.

---

### **Independent Switch Control Board (Secondary PCB) Summary**

The purpose of this independent board is:
* **Start Button Integration:** The start button circuit is **independently connected to the Jetson Orin Nano's GPIO interface**, ensuring the main controller detects the start command as per regulations.
* **Debugging and Status Display:** An **RGB LED was added** to the board to optimize the debugging process.
* **Function:** The LED is used to **display the color of the nearest object detected by the vehicle in real-time**, facilitating quick diagnostics and status monitoring.
* **Role:** **This board is dedicated to the autonomous car's start button control and status indication**.

 <div align=center>
 <table>
    <tr>
      <th colspan=3>Switch Control Circuit Board (Secondary PCB)</th>
      </tr>
      <tr>
      <th>3D view</th>
      <th>circuit schematic</th>
      <th>PBC layout drawing</th>
      </tr>
      <tr>
      <td align=center ></td>
         <td align=center ></td>
         <td align=center ></td>
      </tr>
      <tr>
      <th align=center colspan=3>	Overall circuit schematic  </th> 
      </tr>
      <tr>
    <td align=center colspan=3>
   </td>
   </tr>
      </tr>
      </table>
      </div>

<div align=center>
    <table>
        <tr>
            <th colspan=2>Lens Mount with Integrated Light Shielding Functionality</th>
        </tr>
        <tr>	
            <th>Lens Mount</th>
            <th>Lens Module Fine-Tuning Mechanism</th>
        </tr>
        <tr>
            <td align=center width=500></td>
            <td align=center width=500></td>
        </tr>
        <tr>	
            <th>Lens Mount Physical Side View</th>
            <th>Lens Mount Physical Front View</th>
        </tr>        
        <td align=center width=500></td>
        <td align=center width=500></td>
        </tr>
    </table>
</div>

 ## 2025/10/18 ~ 2025/10/24
 **Member:** HU,SIAN-YI, LIN ZHAN-RONG, ZHANG YI-WEI

 **Content:**

### **Infrared Sensor-Assisted Parking and Signal Reading** 

This week, we implemented the **parking procedure using the infrared sensors installed on the front and rear of the robot**.

The **analog signal reading procedure for the infrared sensors** is shown below.

 ```python
    class TCRT5000:
        def __init__(self, adc_pin):
            try:
                self.adc = ADC(Pin(adc_pin))
            except:
                self.adc = None
        def read_raw(self):
            try:
                return self.adc.read_u16()
            except:
                return -1
        def read_percentage(self):
            try:
                raw = self.read_raw()
                if raw == -1:
                    return -1
                percentage = (raw / 65535) * 100
                return round(percentage, 1)
            except:
                return -1
  ```

 ## 2025/10/25 ~ 2025/10/31
 **Member:** HU,SIAN-YI, LIN ZHAN-RONG, ZHANG YI-WEI

 **Content:**
### **Final Program Architecture Completion and Video Production** 

* **Final Architecture and Flow:** This week, we have **completed the final program architecture**. Following previous hardware and logic modifications, our **parking procedure flow has also undergone slight adjustments and optimization**. The diagram below illustrates the **sequential flow of the final version of the parking procedure**.
* **Video Production:** After finalizing the program architecture and procedures, we also **commenced the filming of the introduction video**.
    * **[5-1 Open Challenge rounds](video/Open_Challenge/video.md)**
    * **[5-2 Obstacle Challenge rounds](video/Obstacle_Challenge/video.md)**

 <div align=center>
    <table>
        <tr>
            <th>Final Version Parking Procedure Flow Diagram.</th>
        </tr>
        <tr>
            <td width=1000 align=center></td>
        </tr>
    </table>
 </div>

 ## 2025/11/01 ~ 2025/11/07
 **Member:** HU,SIAN-YI, LIN ZHAN-RONG, ZHANG YI-WEI

 **Content:**
 
**All team members, working diligently overnight in accordance with their previously allocated responsibilities, are urgently continuing to upload the modified engineering documentation to the GitHub project repository**.

<div align=center>
    <table>
        <tr align=center>
            <td colspan=3></td>
        </tr>
        <tr align=center>
            <td></td>
            <td></td>
            <td></td>
        </tr>
    </table>
</div>

 ## 2025/11/08 ~ 2025/11/14
 **Member:** HU,SIAN-YI, LIN ZHAN-RONG, ZHANG YI-WEI

 **Content:**

### **Communication Protocol Adjustment and Ongoing Engineering Document Updates**

#### **1. Communication Protocol Adjustment Decision and New Challenge**
   - Following confirmation with the **World Final judges** a few days ago, the communication between the main and auxiliary controllers (**Jetson Orin Nano** and **Raspberry Pi Pico W**) **is prohibited from using stable wireless communication protocols such as WebSocket**.

   - Given this rule restriction, we decided to **abandon the previously investigated WebSocket solution** and **revert to the established UART (Universal Asynchronous Receiver-Transmitter) communication protocol** for data transmission.

   - However, since the main controller has been upgraded to the **Jetson Orin Nano**, and we **have not yet implemented UART communication on this specific controller**, this presents a **new technical challenge** for the team.

#### **2. Engineering Document Progress**
   - **Continuing to modify engineering documentation on the GitHub project repository**.

 # <div align="center">HOME[Return Home](../../)</div>

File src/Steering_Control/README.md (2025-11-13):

<div align=center> logo </div>

## <div align="center">Steering Control Overview</div> 

 - ### Vehicle steering control
    
    1. **Direction Determination**:
        * The system uses the **Jetson Orin Nano controller** to read the image stream from the **CSI camera**. It then utilizes the designated **Region of Interest (ROI4)** to detect the **orange and blue lines** on the track, thereby determining whether the vehicle should execute a **left turn or a right turn**.
        * **Right Turn Decision:** If the **contour area of the detected orange line (maxO)** **exceeds the preset threshold (> 110)**, the system decides that a **right turn ("right")** is required.
        * **Left Turn Decision:** If the **contour area of the detected blue line (maxB)** **exceeds the preset threshold (> 110)**, the system decides that a **left turn ("left")** is required.
    2. **Curve Entry Signal**:
        * **Condition Check:** Once the system **confirms the intended turning direction** and **detects the corresponding turn line marker** (e.g., if a right turn is intended, the condition **`maxO > 100`** must be met), the system determines that curve entry is necessary.
        * **Flag Setting:** Subsequently, the system sets the primary **turning signal flag (`tSignal = True`)**, and simultaneously sets the **`rTurn` (right turn) or `lTurn` (left turn) flag** according to the direction, signaling the control logic to begin the turning maneuver.
    3. **Curve Auxiliary Detection and Avoidance Mechanism**:
        * **Trigger Condition:** When the **contour area of the wall on either side** (**`leftArea` (from ROI1) or `rightArea` (from ROI2)**) **exceeds the preset threshold of 1000**, the system determines that the vehicle is too close to the wall.
        * **Dynamic ROI Adjustment:** The system automatically activates a **smaller, high-sensitivity Region of Interest (ROI5)**, with coordinates `[270, 110, 370, 150]`, specifically designed to **enhance the detection of black and magenta contours**.
        * **Outer Wall Contact Reaction:** As soon as **ROI5 detects contact with the outer wall**, the system immediately **increases the steering angle**, causing the vehicle to turn more sharply to **prevent the vehicle body from colliding with the outer wall**.

   - ### **program code:**
    ```python
    if turnDir == "none":
        # If orange line is seen, start a right turn.
        if maxO > 100:
            # Set turn direction.
            turnDir = "right"
        # If blue line is seen, start a left turn.
        elif maxB > 100:
            # Set turn direction.
            turnDir = "left"
    # If a turn is active and the correct line is still visible:
    if (turnDir == "right" and maxO > 100) or (turnDir == "left" and maxB > 100):
        # Record the lap count when the turn started.
        t2 = t
        # Special case for lap 7 (adjust ROI3).
        if t2 == 7 and not pillarAtStart:
            # Move ROI3 (pillars) up.
            ROI3[1] = 110
        # If a pillar is visible during the turn:
      if cPillar.area != 0 and turnDir == "left" or cPillar.area != 0 and turnDir == "right":
      #cPillar.area != 0 and ((leftArea > 1000 and turnDir == "left")
       or (rightArea > 1000 and turnDir == "right"))
            # Activate ROI5 (turn helper).
            ROI5 = [270, 110, 370, 150]
        # If it's a right turn:
        if turnDir == "right":
            # Set the right turn flag.
            rTurn = True
        # If it's a left turn:
        else:
            # Set the left turn flag.
            lTurn = True
        # At t=0, check if there was a pillar at the start line.
        if t == 0 and pillarAtStart == -1:
            # Set the pillarAtStart flag.
            pillarAtStart = True
            if ((startArea > 2000 and startTarget == greenTarget) or
               (startArea > 1500 and startTarget == redTarget)) else False
        # Set the signal flag.
        tSignal = True
    # Check for "wrong" line detection (e.g., blue during a right turn).
    elif (turnDir == "left" and maxO > 100) or (turnDir == "right" and maxB > 100):
        # Special case for lap 11 (related to 's' state).
        if t2 == 11:
            # Set 's' state.
            s = 2
            # Record timestamp for 's' state.
            sTime = time.time()
    ```
     <div align=center>
      <table>
      <tr>
      <th  align=center width="50%">Blue Line Detected in ROI4</th>
      <th  align=center width="50%">Orange Line Detected in ROI4</th>
      </tr><tr>
      <td  align=center width="50%"></td>
      <td  align=center width="50%"></td>
      </tr>

      <tr>
      <th  align=center width="50%">Performing Avoidance Maneuvers Upon Traffic Signal Detection</th>
      <th  align=center width="50%">Performing Turns Without Traffic Signal Detection</th>
      </tr><tr>
      <td  align=center width="50%"></td>
      <td  align=center width="50%"></td>
      </tr>

      <tr>
      <th  align=center width="50%">Activation of Auxiliary ROI5 Triggered by Inner Wall Detection During Turning Mode</th>
      <th  align=center width="50%">Executing Evasion Maneuver Upon Outer Wall Detection by ROI5</th>
      </tr><tr>
      <td  align=center width="50%"></td>
      <td  align=center width="50%"></td>
      </tr>
      </table>
     </div>   

- ### Vehicle Obstacle Avoidance Control
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

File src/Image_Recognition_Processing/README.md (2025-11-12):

<div align="center">logo</div>

## <div align="center">Image Recognition Processing</div> 

  - There are six colors on the competition field—red, green, blue, orange, magenta, and black—which must be located via image recognition so the Vehicle can smoothly avoid obstacles or complete the assigned tasks.
  - We will use the popular image recognition software OpenCV to recognize objects on the competition field.
  
### Using LAB for Color Detection in OpenCV ([Color_LAB.py](../Programming/common/Color_LAB.py))
  - To perform color detection, we convert the RGB color space to LAB and define lower and upper LAB thresholds to establish a range, ensuring accurate target detection. The specific steps are as follows:

  1. **Color Conversion**:  
    Use `cv2.cvtColor(image, cv2.COLOR_BGR2LAB)` to convert the RGB image to the LAB color space. L denotes lightness, ranging from 0 (black) to 100 (white); A denotes the red–green component (positive toward red, negative toward green); B denotes the yellow–blue component (positive toward yellow, negative toward blue). The key to using LAB for color recognition is separating lightness L from the chromatic channels A and B. In practice, you only need to tune the color thresholds on A and B to robustly filter the target color, while L can be adjusted to account for shadows, reflections, and exposure on site without interfering with color judgment.
  2. **Adjust Color-detection Thresholds**:  
    Use `cv2.getTrackbarPos()` to read the real-time values from sliders (typically used with OpenCV’s window UI). The sliders can dynamically adjust the threshold parameters L HIGH, L LOW, A HIGH, A LOW, B HIGH, and B LOW. Tuning parameters on live video makes the process more intuitive and faster.
  3. **Filter The Target Color**:  
    Use `cv2.inRange()` to set the lower and upper bounds of the color range and create a binary mask image. Pixels outside the range are set to black (value 0), which suppresses noise and preserves only the regions of the target color for subsequent processing and analysis.
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

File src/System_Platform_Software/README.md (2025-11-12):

<div align=center> logo </div>

## <div align="center">Software Platform Construction </div> 
- ### __Installing System Software Required for Self-Driving Cars__

   - ### Self-Driving Car Operating System Installation Flowchart

   <div align=center>
   
   </div>

   - ### Installing the Operating System on Nvidia Jetson Orin Nano
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

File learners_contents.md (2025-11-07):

<div align="center">logo</div> 

## For Learners ## 

- ### Hardware Selection
    - [Main Controller Comparison](./schemes/Main_Controller_Choosing/README.md)
    - [Motor & Sensor Intermediate I/O Controller Comparison](./schemes/Motor_Sensor_Controller_Choosing/README.md)
    - [Motor Selection](./schemes/Motor/README.md)
    - [Ultrasonic rangefinder](./schemes/HC-SR04/README.md)
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

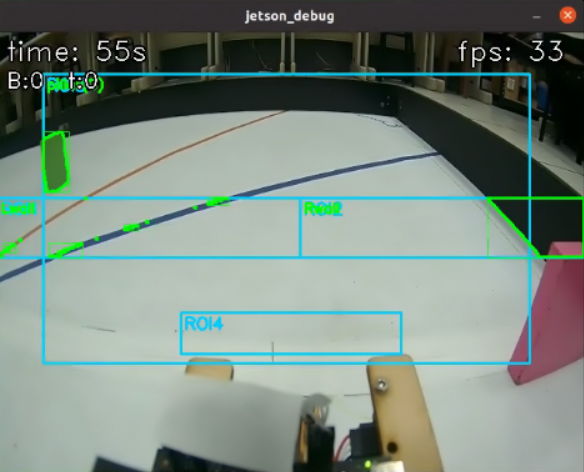
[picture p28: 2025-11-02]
src/Overview_of_Parking_Lot_Departure_Steering_Control/img/Counter-clockwise uncolored route.png

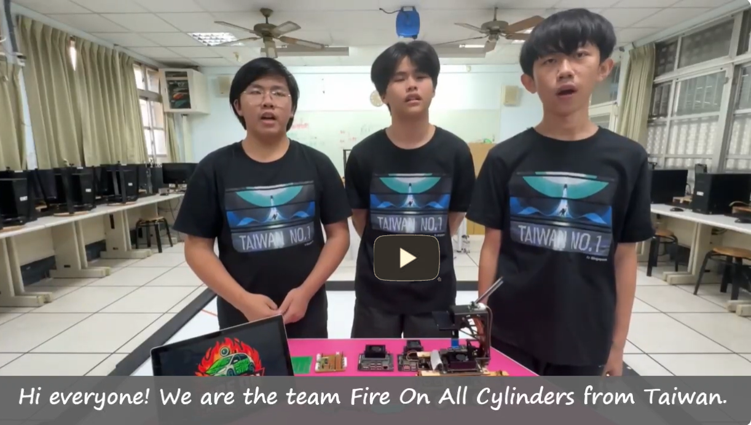
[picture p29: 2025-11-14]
video/Design_Process_Video/img/all.png

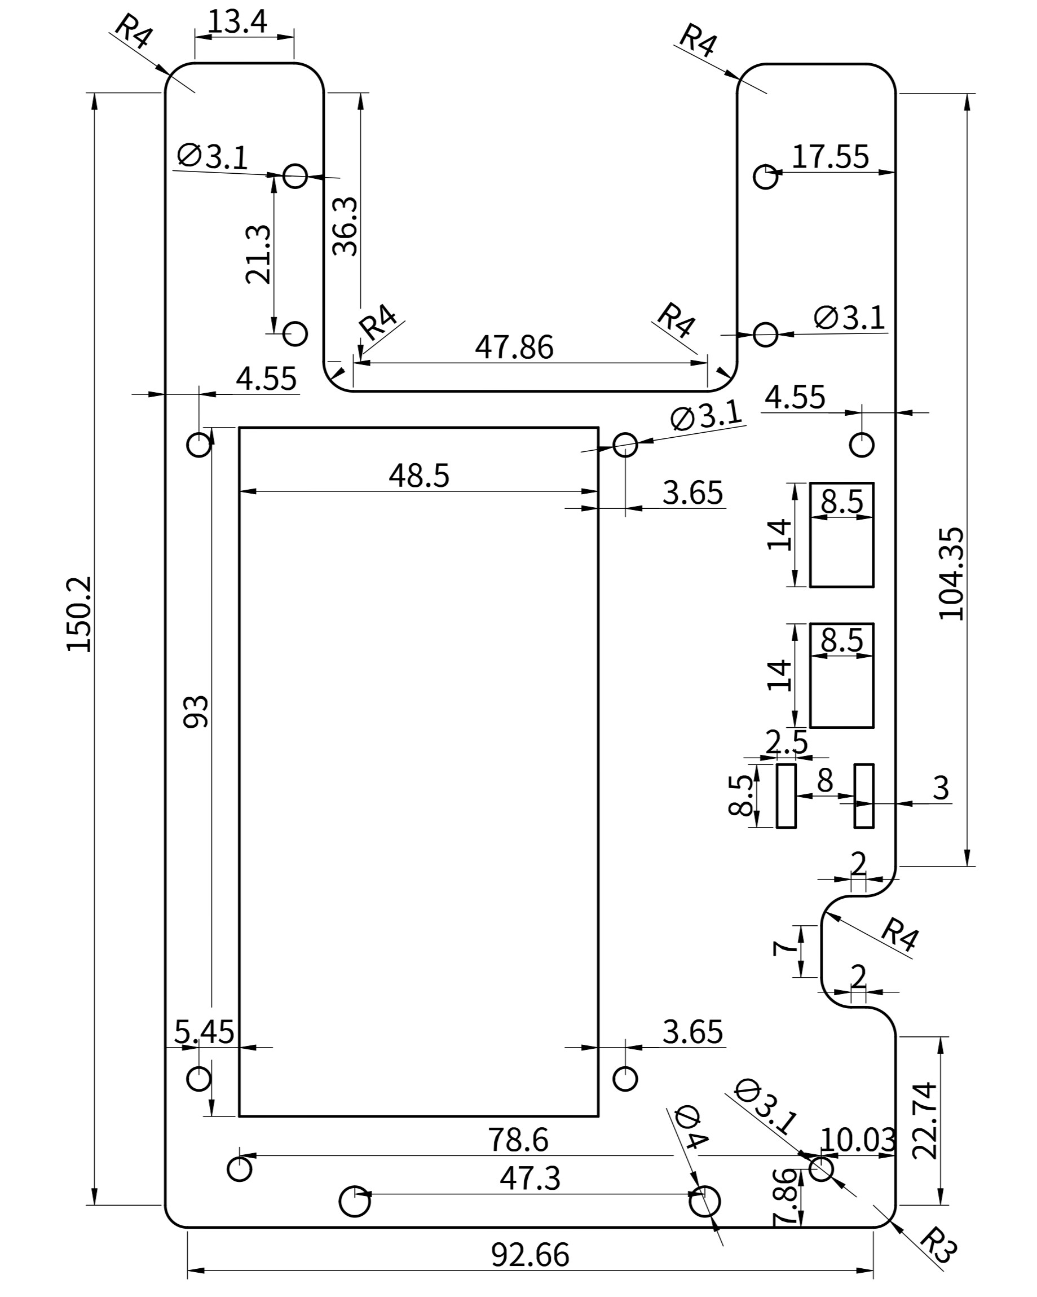
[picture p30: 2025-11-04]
models/Vehicle_2D_3D/Vehicle_Chassis_Sizse/img/2D_top_size.jpg

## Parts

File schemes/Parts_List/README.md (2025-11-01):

<div align="center">logo</div>  

## <div align="center">BOM Part List </div>
<li><a href="https://pse.is/87lasz" target="_blank">NVIDIA Jetson Orin Nano SUPER Developer Kit 8GB </li> 
<li><a href="https://pse.is/87lask" target="_blank">Raspberry Pi Pico W RP2040</li> 
<li><a href="https://pse.is/87lagc" target="_blank">L293d motor controller</li>
<li><a href="https://pse.is/87lar6" target="_blank">MG513-P30 293RPM DC reduction motor</li>  
<li><a href="https://sho.pe/87layg" target="_blank">12-tooth Plastic gear</li>
<li><a href="https://pse.is/87lazf" target="_blank">MG90s servo motor</li>    
<li><a href="https://pse.is/87lb25" target="_blank">Micro switch 6*6*10</li>  
<li><a href="https://pse.is/87lb2s" target="_blank">Lipo battery low voltage alarm </li>  
<li><a href="https://sho.pe/87lb3h" target="_blank">Ship-type switch</li>     
<li><a href="https://sho.pe/87lb3u" target="_blank">SONY IMX477 camera module</li>
<li><a href="https://sho.pe/87lb4b" target="_blank">Li-Polymer battery 3S Desire Power V8 11.1V 1300mAh 70C </li>
<li><a href="https://pse.is/87lb53" target="_blank">Amass TX60-M plug</li>
<li><a href="https://pse.is/87lcxx" target="_blank">High current 5A constant voltage constant current buck power supply module</li>  
<li><a href="https://sho.pe/87lcwl" target="_blank">Lego 62821b Differential Gear</li>
<li><a href="https://sho.pe/87ld2t" target="_blank">695ZZ bearing M5x13x4 NSK</li>
<li><a href="https://pse.is/87ld8g" target="_blank">2.5mm Connector 2 Pin Male Adapter Right Angle Pin Header White Socket</li>
<li><a href="https://pse.is/87ld9b" target="_blank">2.5mm Connector 3 Pin Male Adapter Right Angle Pin Header White Socket</li>
<li><a href="https://pse.is/87lda4" target="_blank">2.5mm Connector 4 Pin Male Adapter Right Angle Pin Header White Socket</li>
<li><a href="https://pse.is/87ldam" target="_blank">2.5mm Connector 6 Pin Male Adapter Right Angle Pin Header White Socket</li>
<li><a href="https://pse.is/87ldbx" target="_blank">2.5mm Connector 2 Pin female Adapter Right Angle Pin Header White Socket</li>
<li><a href="https://pse.is/87ldcg" target="_blank">2.5mm Connector 3 Pin female Adapter Right Angle Pin Header White Socket</li>
<li><a href="https://pse.is/87ldcw" target="_blank">2.5mm Connector 4 Pin female Adapter Right Angle Pin Header White Socket</li>
<li><a href="https://pse.is/87ldd9" target="_blank">2.5mm Connector 6 Pin female Adapter Right Angle Pin Header White Socket</li>
<li><a href="https://pse.is/87ldgf" target="_blank">White Plastic Nylon M3x25+6mm Hex Column Standoff Support Male-Female</li>
<li><a href="https://pse.is/87ldgq" target="_blank">White Plastic Nylon M3x15+6mm Hex Column Standoff Support Male-Female</li>
<li><a href="https://pse.is/87ldgw" target="_blank">White Plastic Nylon M3x8 +6mm Hex Column Standoff Support Male-Female</li>
<li><a href="https://pse.is/87ldha" target="_blank">White Plastic Nylon M3x6 +6mm Hex Column Standoff Support Male-Female</li>
<li><a href="https://pse.is/87ldhf" target="_blank">Internal Phillips Head Plastic screw M3x5mm</li>
<li><a href="https://pse.is/87ldhu" target="_blank">Plastic Nut M3</li>
<li><a href="https://sho.pe/87ldr4" target="_blank">Internal Hexagonal Metal Screw M3x10mm</li>
<li><a href="https://sho.pe/87ldsn" target="_blank">Matal Nut M3</li>
<li><a href="https://sho.pe/87ldvk" target="_blank">Matal Nut M2</li>
<li><a href="https://www.icshop.com.tw/products/368020100979?locale=en" target="_blank">GSP001S-5.08-02P-11-00A(H)</li>
<li><a href="https://www.icshop.com.tw/products/368020100986" target="_blank">5.08mm Euro-style Terminal 2P Male 180°</li>
<li><a href="https://pse.is/87ldkw" target="_blank">Light curing resin Rock-Black Stiff steering knuckle</li>
<li><a href="https://pse.is/87ldl4" target="_blank">Light curing resin Rock-Black Stiff drive shaft</li>
<li><a href="https://pse.is/87ldle" target="_blank">Light curing resin Rock-Black Stiff gearbox</li>
<li><a href="https://pse.is/87ldlm" target="_blank">Light curing resin Aqua-Gray 8K rudder</li>
<li><a href="https://pse.is/87ldlw" target="_blank">Light curing resin Aqua-Gray 8K axle</li>
<li><a href="https://pse.is/87ldm3" target="_blank">Light curing resin Speed motor bracket</li>
<li><a href="https://pse.is/87ldm8" target="_blank">Light curing resin Speed windshield</li>
<li><a href="https://pse.is/87ldme" target="_blank">Wood board, thickness 3mm (bottom layer)</li>
<li><a href="https://pse.is/87ldmn" target="_blank">Wood board, thickness 3mm (middle layer)</li>
<li><a href="https://pse.is/87ldmw" target="_blank">Wood board, thickness 3mm (top layer)</li>
<li><a href="https://pse.is/87ldn8" target="_blank">HC-SR04</li>
<li><a href="https://pse.is/87ldnk" target="_blank">BNO055</li>
<li><a href="https://pse.is/8af85m" target="_blank">TCRT5000</li>
<li><a href="https://sho.pe/87ldnp" target="_blank">USB 3.0 Male to Female 90-Degree Angle Adapter</li>

# <div align="center">HOME[Return Home](../../)</div>

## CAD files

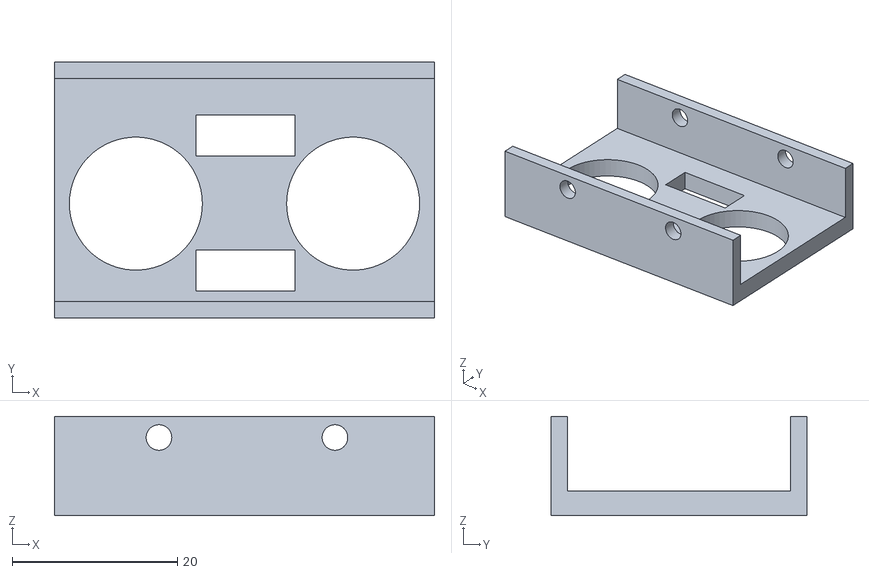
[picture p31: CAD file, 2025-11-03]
models/Vehicle_2D_3D/Vehicle_Chassis_CAD_File/Ultrasonic_Stent.stl
46.0 x 31.0 x 12.0

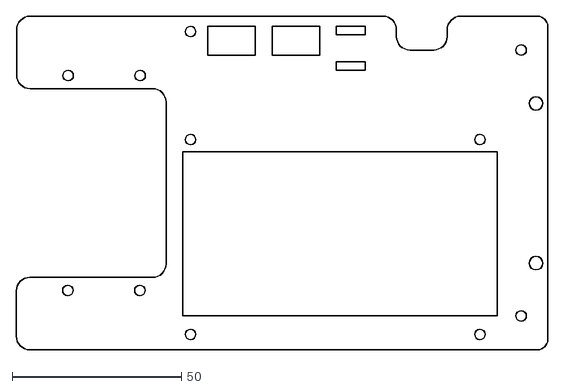
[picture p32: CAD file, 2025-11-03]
models/Vehicle_2D_3D/Vehicle_Chassis_Sizse/top.dxf
157.2 x 98.7

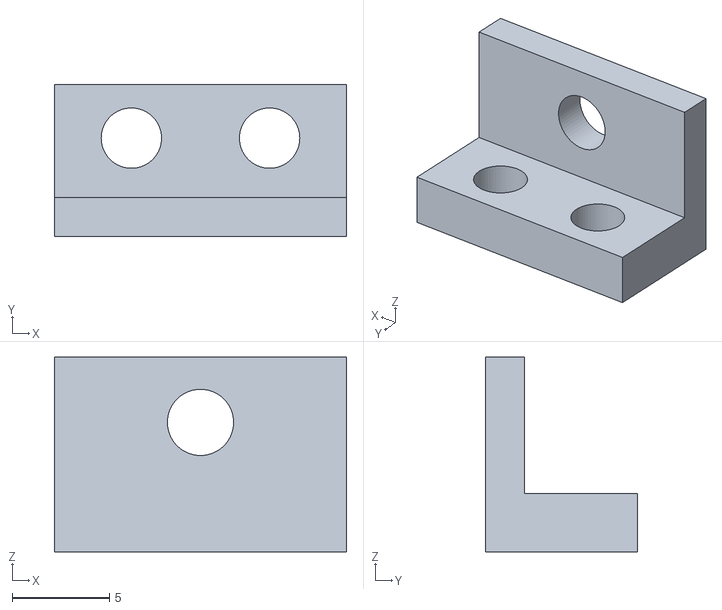
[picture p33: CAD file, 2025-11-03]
models/Vehicle_2D_3D/Vehicle_Chassis_CAD_File/Infrared_Bracket.stl
15.0 x 7.80 x 10.0

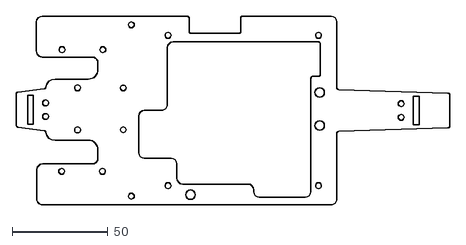
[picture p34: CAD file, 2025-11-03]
models/Vehicle_2D_3D/Vehicle_Chassis_Sizse/mid.dxf
226.5 x 98.7

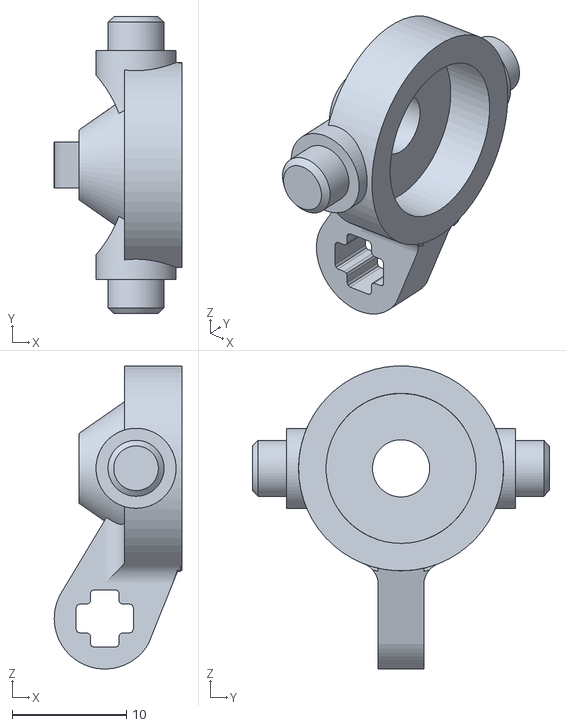
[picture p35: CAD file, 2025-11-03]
models/Vehicle_2D_3D/Vehicle_Chassis_CAD_File/steering_knuckle.stl
11.2 x 26.0 x 26.5

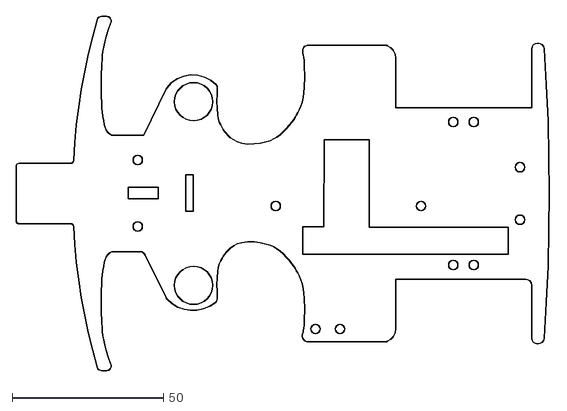
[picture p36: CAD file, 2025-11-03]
models/Vehicle_2D_3D/Vehicle_Chassis_Sizse/bottom.dxf
177.1 x 117.2

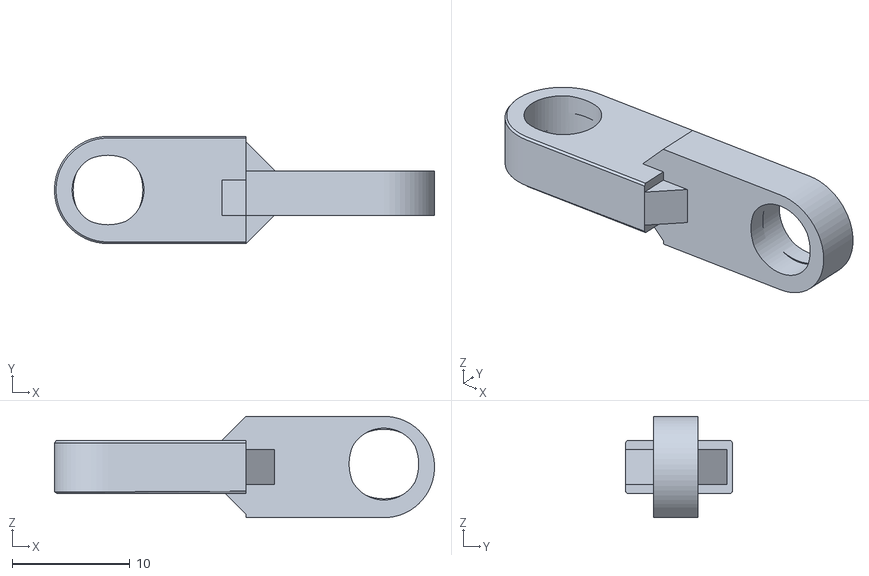
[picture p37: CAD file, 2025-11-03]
models/Vehicle_2D_3D/Vehicle_Chassis_CAD_File/Steering_rod.stl
32.2 x 9.10 x 8.60

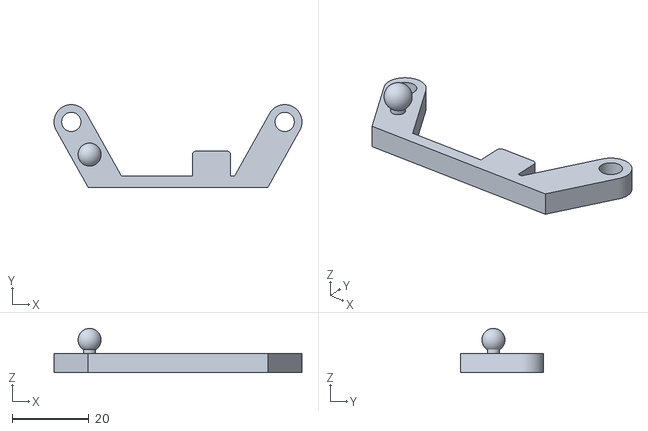
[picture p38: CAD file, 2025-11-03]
models/Vehicle_2D_3D/Vehicle_Chassis_CAD_File/steering_crossbar.stl
64.5 x 21.5 x 11.5

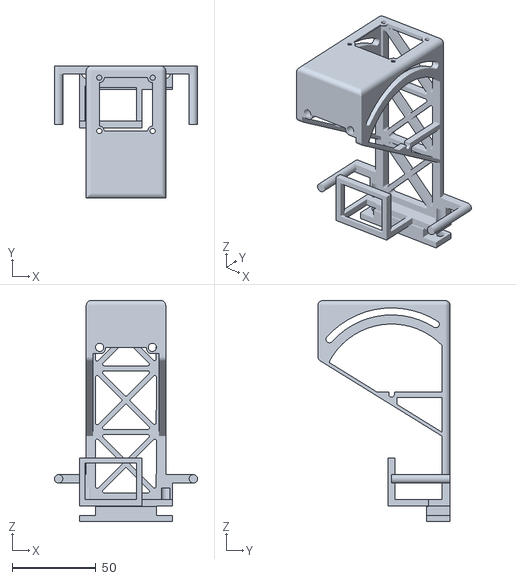
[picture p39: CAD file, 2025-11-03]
models/Vehicle_2D_3D/Vehicle_Chassis_CAD_File/Camera_bracket.stl
85.5 x 79.0 x 132.0

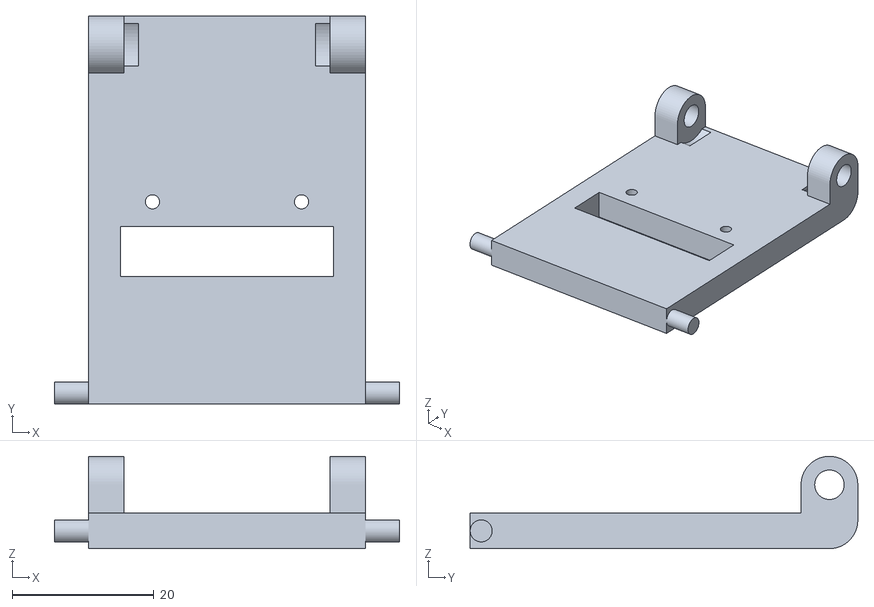
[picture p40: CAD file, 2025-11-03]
models/Vehicle_2D_3D/Vehicle_Chassis_CAD_File/Camera_mounting_plate.stl
48.6 x 54.6 x 13.0

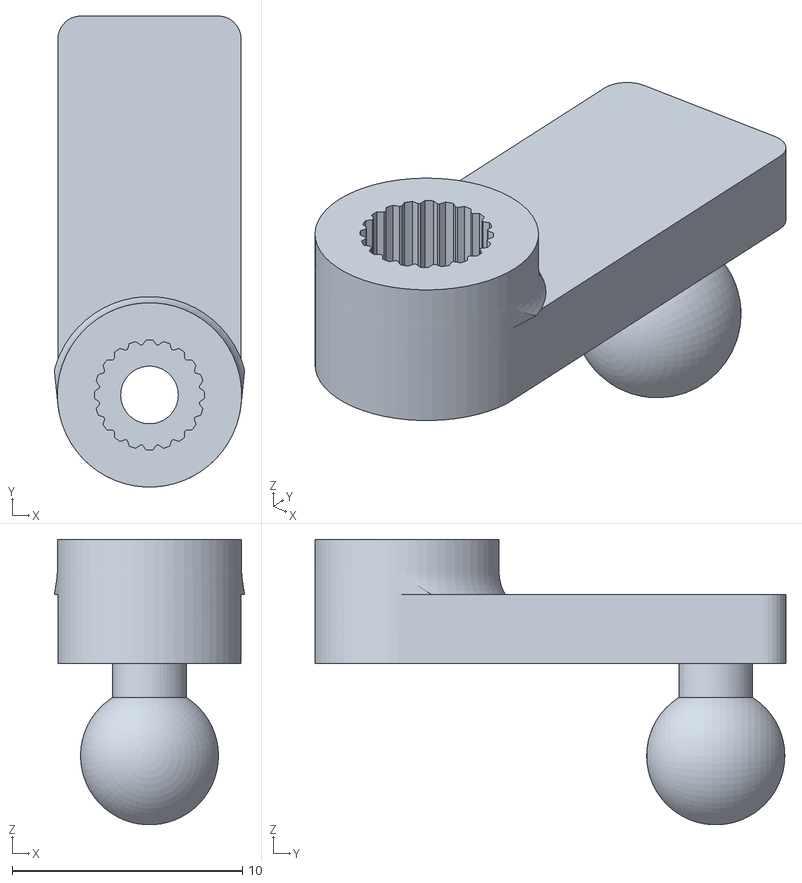
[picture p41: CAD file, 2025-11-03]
models/Vehicle_2D_3D/Vehicle_Chassis_CAD_File/steering_wheel.stl
8.26 x 20.4 x 12.4

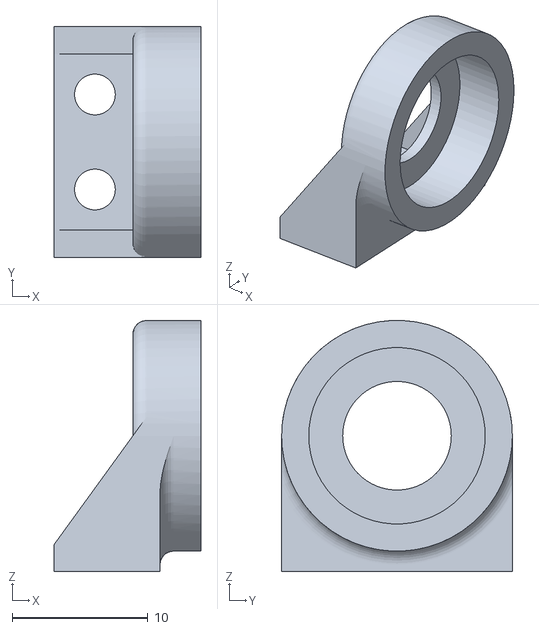
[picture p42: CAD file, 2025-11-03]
models/Vehicle_2D_3D/Vehicle_Chassis_CAD_File/Bearing_bracket.stl
10.8 x 17.0 x 18.5

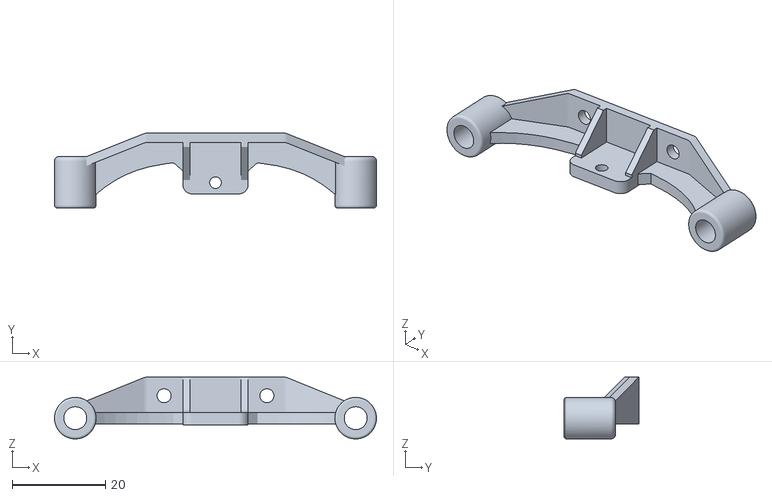
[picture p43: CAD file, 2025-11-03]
models/Vehicle_2D_3D/Vehicle_Chassis_CAD_File/steering_knuckle_bracket.stl
68.9 x 16.0 x 13.2

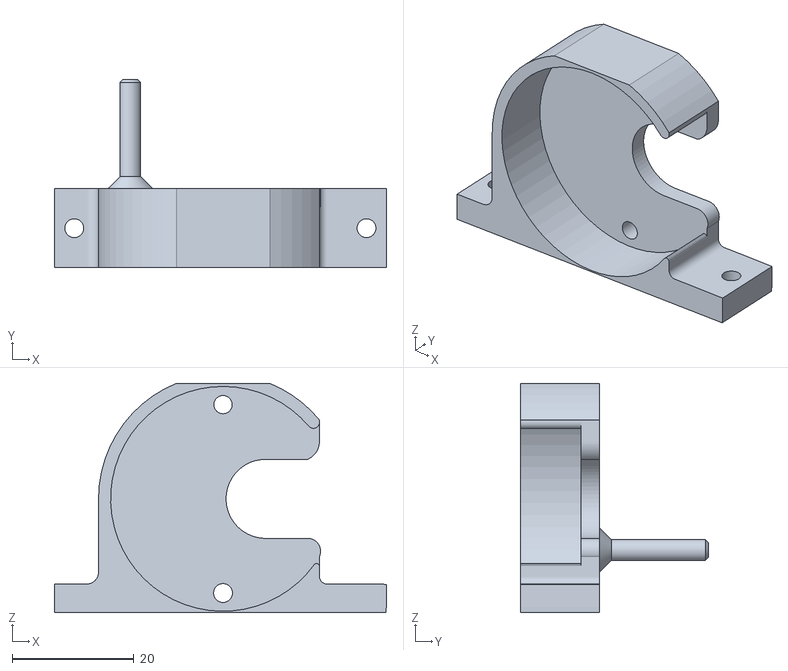
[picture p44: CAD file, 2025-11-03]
models/Vehicle_2D_3D/Vehicle_Chassis_CAD_File/Motor_Bracket.stl
54.6 x 31.0 x 37.7

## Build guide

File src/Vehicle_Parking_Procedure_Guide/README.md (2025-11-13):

<div align="center">logo</div>

## <div align="center">Vehicle Parking Procedure Guide</div>
###  **Code Logic Description: Parking Task After Three Laps**
- ### Parking program
    
    1.  **Parking Zone Identification and Entry Preparation (Jetson Orin Nano)**
      * While the vehicle is driving, the **Jetson Orin Nano system** continuously identifies the **precise location of the parking lot** by detecting the **magenta square** via the camera.
      * When the vehicle **completes the third lap**, the autonomous car executes a **turn to enter the parking zone** and continues to **drive forward** until the **infrared sensor detects a wall**. At this point, the vehicle immediately performs a **reverse turn** and adjusts its body orientation towards the parking lot's precise direction.

    2.  **Precise Positioning and Bay Entry Start (Jetson Orin Nano)**
      * Once the vehicle is oriented towards the parking area, the **Jetson Orin Nano** **measures the lateral distance** between the vehicle and the **magenta parking bay marker** in real-time via the camera, ensuring an appropriate entry gap is maintained.
      * To confirm the vehicle has reached the **precise entry starting position**, the program continuously monitors the **area of the magenta marker** captured by the camera.
      * Once the **area of the magenta region is less than 100**, the positioning is confirmed. The vehicle then continues to **follow the wall line for 100 degrees** , followed by executing the **turning action to enter the parking bay**.

    3.  **Parallel Reverse Parking and Attitude Control (Raspberry Pi Pico W)**
      * After confirming the target parking direction, the system executes a maneuver that **simulates real-world parallel parking**.
      * First, the **Jetson Orin Nano** calculates and sets the **initial angle of the steering servo motor** and the **value for the DC drive motor**.
      * During the reverse parking maneuver, the **main control unit (Raspberry Pi Pico W)** is responsible for **reading the gyroscope angle data** from the Jetson Orin Nano (or directly implementing attitude control), which allows for **precise control over the vehicle's posture and steering angle**. The Pico W simultaneously adjusts the servo motor, thereby **completing the automatic parallel reverse parking action**.    

- **Code Executed on the Raspberry Pi Pico W Controller**
    ``` python
    while mode == 3:
        json_obj, _, got_stop = pump_uart(s) # Pump UART for data
        extract_magenta_from_json(json_obj) # Update magenta data
        while abs(yaw) < 85: # Loop while yaw is less than 85 degrees
            json_obj, _, got_stop = pump_uart(s) # Pump UART for data
            if json_obj:
                if "yaw" in json_obj:
                    try:
                        yaw = float(json_obj["yaw"]) # Update yaw
                    except:
                        pass
                extract_magenta_from_json(json_obj) # Update magenta data
            if turn == 2: # Turn 2 (e.g., Left start)
                set_servo_angle(45) # Set servo angle
                control_motor(35) # Set motor speed
            else: # Turn 1 (e.g., Right start)
                set_servo_angle(-40) # Set servo angle
                control_motor(35) # Set motor speed                 
        motor_brake() # Stop motor
        set_servo_angle(0) # Center servo
        mode = 4 # Change mode

    while mode == 4:
        a0_value = A0.read_u16() # Read ADC A0 value
        time_a0=time.time() # Record start time
        # Loop while A0 value is high and time limit not reached
        while a0_value > 64800 and time.time()- time_a0 < 5: 
            a0_value = A0.read_u16() # Read ADC A0 value
            extract_magenta_from_json(json_obj) # Update magenta data 
            json_obj, _, got_stop = pump_uart(s) # Pump UART for data
            if json_obj:
                if "yaw" in json_obj:
                    try:
                        yaw = float(json_obj["yaw"]) # Update yaw
                    except:
                        pass
                extract_magenta_from_json(json_obj) # Update magenta data  
            set_servo_angle(0) # Center servo
            control_motor(30) # Drive motor forward
        control_motor(-40) # Drive motor backward
        time.sleep(0.1) # Wait for a short time
        control_motor(0) # Stop motor
        mode = 5 # Change mode

    while mode == 5:
        json_obj, _, got_stop = pump_uart(s) # Pump UART for data
        while abs(yaw) < 177: # Loop while yaw is less than 177 degrees
            extract_magenta_from_json(json_obj) # Update magenta data
            json_obj, _, got_stop = pump_uart(s) # Pump UART for data
            if json_obj:
                if "yaw" in json_obj:
                    try:
                        yaw = float(json_obj["yaw"]) # Update yaw
                    except:
                        pass
            if turn == 2: # Turn 2
                set_servo_angle(-180) # Set servo angle
                control_motor(-40) # Drive motor backward
            else: # Turn 1
                set_servo_angle(180) # Set servo angle
                control_motor(-40) # Drive motor backward                  
        motor_brake() # Stop motor
        set_servo_angle(0) # Center servo
        mode = 6 # Change mode
                
    while mode == 6:
        json_obj, m_tuple, got_stop = pump_uart(s) # Pump UART for data
        extract_magenta_from_json(json_obj) # Update magenta data
        while magArea > 70: # Loop while magenta area is greater than 70
            extract_magenta_from_json(json_obj) # Update magenta data
            json_obj, m_tuple, got_stop = pump_uart(s) # Pump UART for data
            if json_obj:
                try:
                    if "leftArea" in json_obj:
                        # Update left area
                        leftArea = int(json_obj.get("leftArea", leftArea)) 
                    if "rightArea" in json_obj:
                        # Update right area
                        rightArea = int(json_obj.get("rightArea", rightArea))
                        except:
                            pass
            if turn ==2: # Turn 2
                if magArea > 3000:
                    error = magCX - 202 # Calculate error based on CX
                    Servo_angle = int(error*0.15 + (error - error1)*0.2) # PD control
                    error1 = error # Update previous error
                    set_servo_angle(Servo_angle) # Set servo angle
                    control_motor(40) # Drive motor forward
                else:
                    error = leftArea - 6500 # Calculate error based on left area
                    Servo_angle = int(error*0.005 + (error - error1)*0.01) # PD control
                    error1 = error # Update previous error
                    set_servo_angle(Servo_angle) # Set servo angle
                    control_motor(40) # Drive motor forward
            else: # Turn 1
                if magArea > 3000:
                    error = magCX - 490 # Calculate error based on CX
                    Servo_angle = int(error*0.13 + (error - error1)*0.2) # PD control
                    error1 = error # Update previous error
                    set_servo_angle(Servo_angle) # Set servo angle
                    control_motor(40) # Drive motor forward
                else:
                    error = 7000 - rightArea # Calculate error based on right area
                    Servo_angle = int(error*0.005 + (error - error1)*0.008) # PD control
                    error1 = error # Update previous error
                    set_servo_angle(Servo_angle) # Set servo angle
                    control_motor(40) # Drive motor forward
        control_motor(-50) # Drive motor backward
        time.sleep(0.1) # Wait for a short time
        control_motor(0) # Stop motor
        time.sleep(0.5) # Wait for a short time
        mode = 7 # Change mode

    while mode == 7:
        json_obj, _, got_stop = pump_uart(s) # Pump UART for data
        while abs(yaw) > 110: # Loop while yaw is greater than 110 degrees
            json_obj, _, got_stop = pump_uart(s) # Pump UART for data
            if json_obj:
                if "yaw" in json_obj:
                    try:
                        yaw = float(json_obj["yaw"]) # Update yaw
                    except:
                        pass
            if turn == 2: # Turn 2  
                set_servo_angle(-180) # Set servo angle
                control_motor(-38) # Drive motor backward
            else: # Turn 1
                set_servo_angle(180) # Set servo angle
                control_motor(-38) # Drive motor backward
        control_motor(50) # Drive motor backward
        time.sleep(0.1) # Wait for a short time
        control_motor(0) # Stop motor
        mode =8 # Change mode 
    while mode == 8:
        json_obj, _, got_stop = pump_uart(s) # Pump UART for data
        a1_value = A1.read_u16() # Read ADC A1 value
        while abs(yaw) < 140 and a1_value > 64800: # Loop while yaw < 140 and A1 is high
            a1_value = A1.read_u16() # Read ADC A1 value
            json_obj, _, got_stop = pump_uart(s) # Pump UART for data
            if json_obj:
                if "yaw" in json_obj:
                    try:
                        yaw = float(json_obj["yaw"]) # Update yaw
                    except:
                        pass
            if turn == 2: # Turn 2  
                set_servo_angle(180) # Set servo angle
                control_motor(-35) # Drive motor backward
            else: # Turn 1
                set_servo_angle(-180) # Set servo angle
                control_motor(-35) # Drive motor backward  
        control_motor(40) # Drive motor forward
        time.sleep(0.1) # Wait for a short time
        control_motor(0) # Stop motor
        set_servo_angle(0) # Center servo
        mode =9 # Change mode
    while mode == 9:
        json_obj, _, got_stop = pump_uart(s) # Pump UART for data
        a0_value = A0.read_u16() # Read ADC A0 value
        while abs(yaw) < 160 : # Loop while yaw is less than 160 degrees
            a0_value = A0.read_u16() # Read ADC A0 value
            json_obj, _, got_stop = pump_uart(s) # Pump UART for data
            if json_obj:
                if "yaw" in json_obj:
                    try:
                        yaw = float(json_obj["yaw"]) # Update yaw
                    except:
                        pass
            if turn == 2: # Turn 2  
                set_servo_angle(-180) # Set servo angle
                control_motor(35) # Drive motor forward
            else: # Turn 1
                set_servo_angle(180) # Set servo angle
                control_motor(35) # Drive motor forward  
        control_motor(-40) # Drive motor backward
        time.sleep(0.1) # Wait for a short time
        control_motor(0) # Stop motor
        set_servo_angle(0) # Center servo
        mode =10 # Change mode 
    while mode == 10:
        json_obj, _, got_stop = pump_uart(s) # Pump UART for data
        a0_value = A0.read_u16() # Read ADC A0 value
        while abs(yaw) < 177 : # Loop while yaw is less than 177 degrees
            a0_value = A0.read_u16() # Read ADC A0 value
            json_obj, _, got_stop = pump_uart(s) # Pump UART for data
            if json_obj:
                if "yaw" in json_obj:
                    try:
                        yaw = float(json_obj["yaw"]) # Update yaw
                    except:
                        pass
            if turn == 2: # Turn 2  
                set_servo_angle(180) # Set servo angle
                control_motor(-35) # Drive motor backward
            else: # Turn 1
                set_servo_angle(-180) # Set servo angle
                control_motor(-35) # Drive motor backward  
        control_motor(40) # Drive motor backward
        time.sleep(0.1) # Wait for a short time
        control_motor(0) # Stop motor
        set_servo_angle(0) # Center servo
        mode =11 # Change mode
    while mode == 11:
        motor_brake() # Apply motor brake
    ```
## <div align="center">Counter-Clockwise Vehicle Parking Procedure </div>
<div align=center>
<table>
<tr>
<th width="50%">The vehicle proceeds forward through the parking area. </th>
<th width="50%"> The vehicle turns to the right, with its front facing the outer wall at a 90-degree azimuth.</th>
</tr>
<tr align=center>
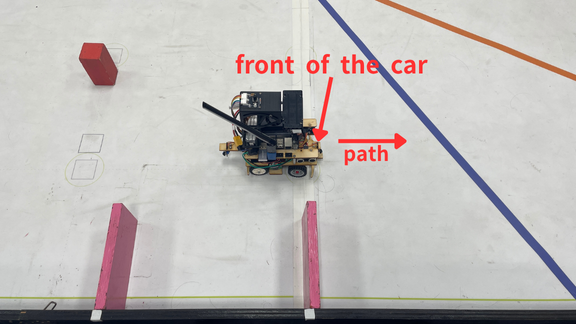
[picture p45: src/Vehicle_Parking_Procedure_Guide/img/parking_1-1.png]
<td width="50%"> </td>
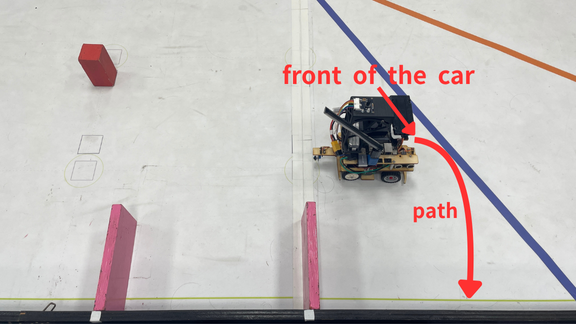
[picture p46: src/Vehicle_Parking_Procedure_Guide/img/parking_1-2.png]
<td width="50%"></td>

</tr>
<tr>
<th width="50%">The vehicle drives straight toward the 90-degree azimuth until the infrared sensor detects the outer wall, then brakes.</th>
<th width="50%">The vehicle reverses towards the left-rear until its yaw angle exceeds 177 degrees.</th>
</tr>
<tr align=center>
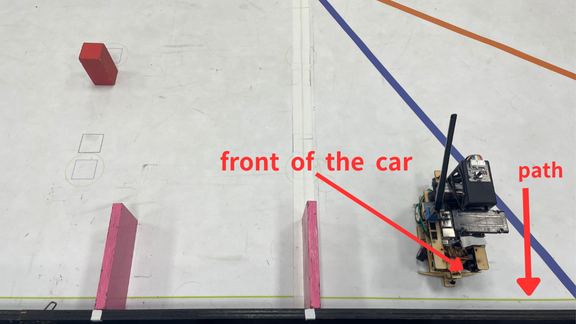
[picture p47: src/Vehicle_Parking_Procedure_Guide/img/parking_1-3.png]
<td width="50%"></td>
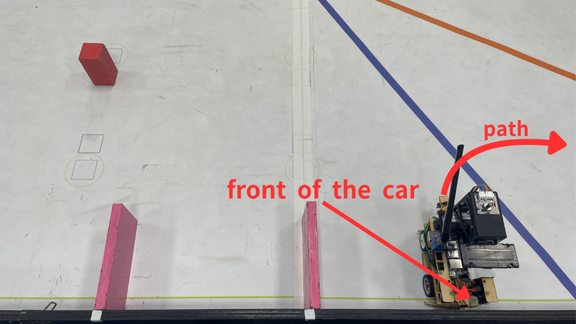
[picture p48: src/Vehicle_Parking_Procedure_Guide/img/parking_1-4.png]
<td width="50%"></td>
</tr>

<tr>
<th width="50%"> The vehicle follows the outer wall until the area of the magenta wall contour is less than 100, then the vehicle moves forward another 100 degrees.</th>
<th width="50%">The vehicle reverses towards the rear-left into the parking area until its heading angle reaches 123 degrees.</th>
</tr>
<tr align=center>
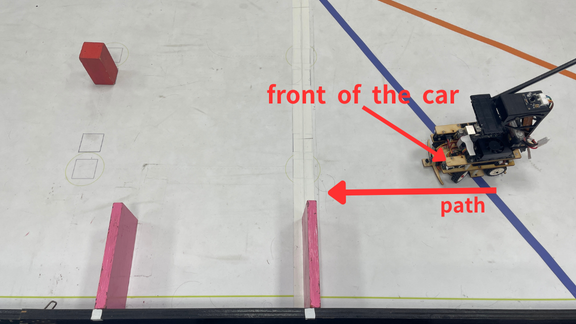
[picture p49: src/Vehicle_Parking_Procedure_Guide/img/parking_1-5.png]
<td width="50%"> </td>
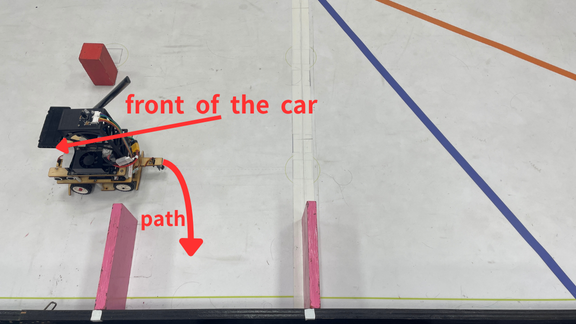
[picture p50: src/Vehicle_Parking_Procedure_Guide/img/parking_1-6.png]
<td width="50%"> </td>
</tr>

<tr>
<th width="50%">The vehicle reverses towards the rear-right into the parking area until its heading angle reaches 177 degrees.</th>
<th width="50%">Vehicle Parking Finished </th>
</tr>
<tr align=center>
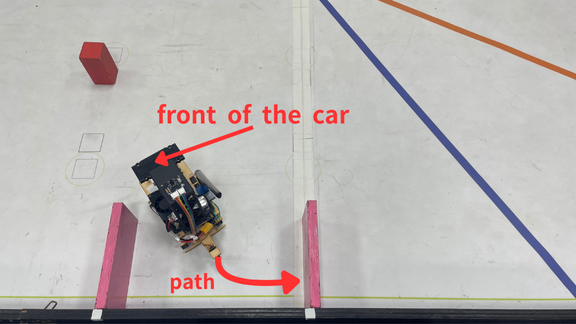
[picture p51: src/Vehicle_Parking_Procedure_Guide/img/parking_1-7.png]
<td width="50%"> </td>
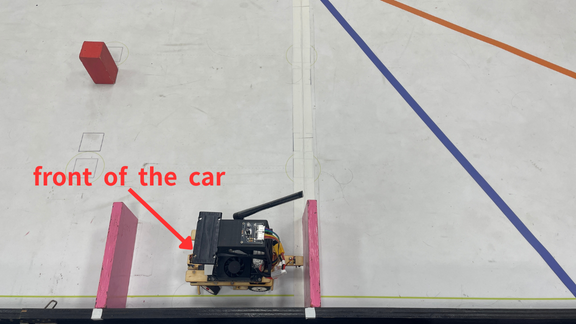
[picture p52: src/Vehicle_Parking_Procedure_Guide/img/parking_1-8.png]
<td width="50%"> </td>
</tr>

<tr>
<th colspan = 2>Video Documentation of the Autonomous Vehicle's Actual Run</th>
</tr>
<tr align=center>
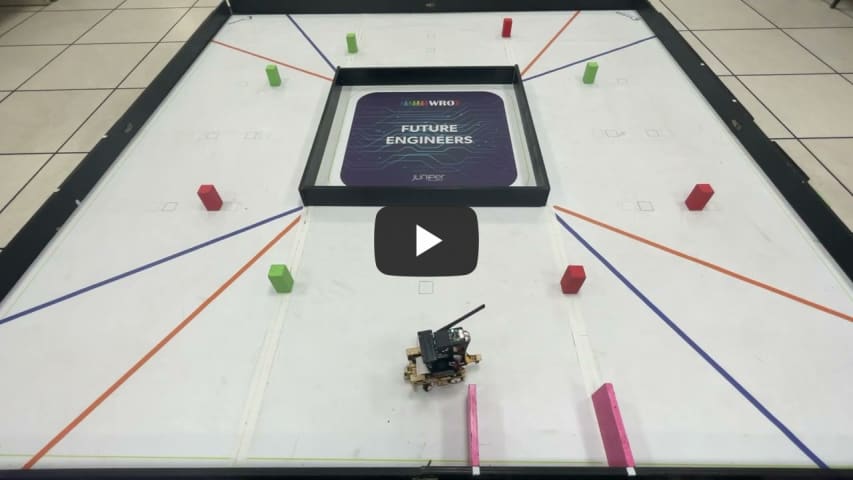
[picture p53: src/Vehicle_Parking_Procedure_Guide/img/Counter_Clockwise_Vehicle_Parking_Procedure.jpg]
Counter_Clockwise_Vehicle_Parking_Procedure
<td colspan = 2></td>

</tr>
</table>
</div>

## <div align="center">Clockwise Vehicle Parking Procedure </div>
<div align=center>
<table>
<tr>
<th width="50%"> The vehicle proceeds forward through the parking area.</th>
<th width="50%"> The vehicle turns to the left, with its front facing the outer wall at a 90-degree azimuth.</th>
</tr>
<tr align=center>
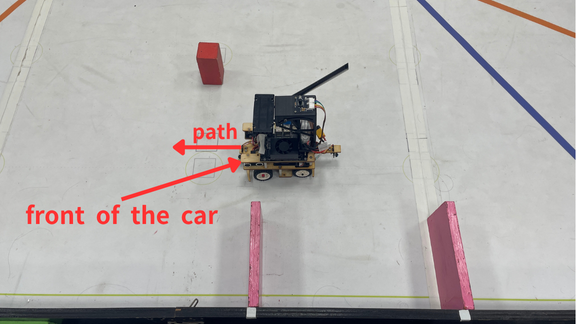
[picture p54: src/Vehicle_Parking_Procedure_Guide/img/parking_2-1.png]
<td width="50%"> </td>
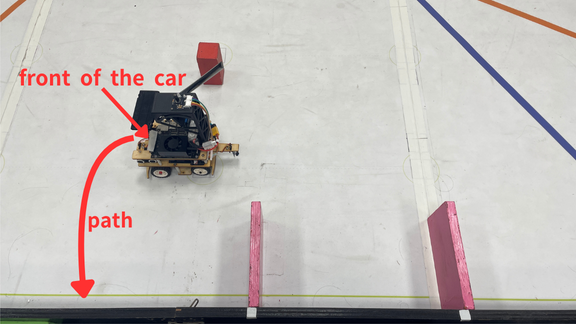
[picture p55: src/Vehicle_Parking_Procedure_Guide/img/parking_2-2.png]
<td width="50%"> </td>
</tr>

<tr>
<th width="50%">The vehicle drives straight toward the 90-degree azimuth until the infrared sensor detects the outer wall, then brakes. </th>
<th width="50%">The vehicle reverses towards the right-rear until its yaw angle exceeds 177 degrees. </th>
</tr>
<tr align=center>
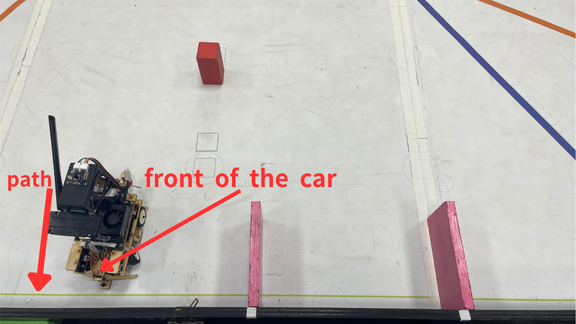
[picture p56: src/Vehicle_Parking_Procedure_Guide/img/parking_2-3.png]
<td width="50%"> </td>
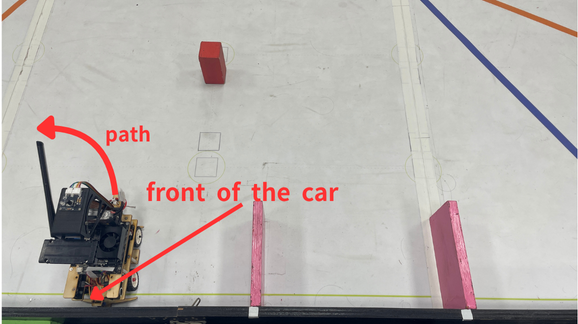
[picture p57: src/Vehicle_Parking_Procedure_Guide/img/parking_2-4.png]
<td width="50%"> </td>
</tr>

<tr>
<th width="50%"> The vehicle follows the outer wall until the area of the magenta wall contour is less than 100, then the vehicle moves forward another 100 degrees.</th>
<th width="50%">The vehicle reverses towards the rear-right into the parking area until its heading angle reaches 123 degrees. </th>
</tr>
<tr align=center>
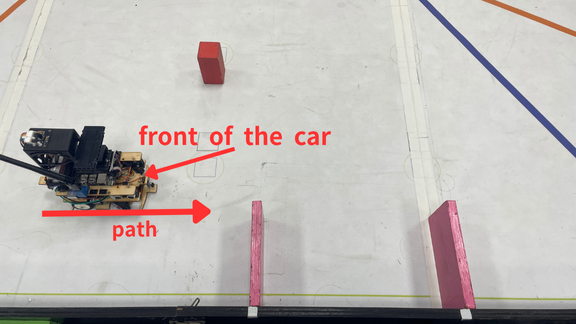
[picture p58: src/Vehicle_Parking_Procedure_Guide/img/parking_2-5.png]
<td width="50%"></td>
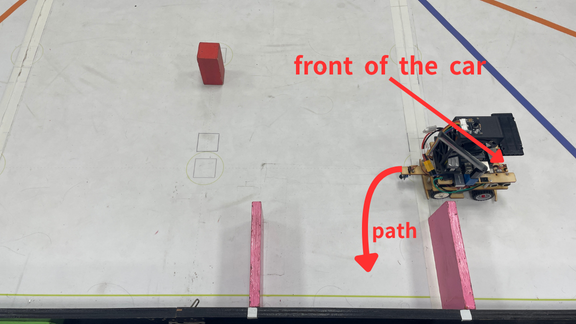
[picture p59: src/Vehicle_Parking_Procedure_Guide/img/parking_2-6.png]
<td width="50%"> </td>
</tr>

<tr>
<th width="50%">The vehicle reverses towards the rear-left into the parking area until its heading angle reaches 177 degrees. </th>
<th width="50%">Vehicle Parking Finished </th>
</tr>
<tr align=center>
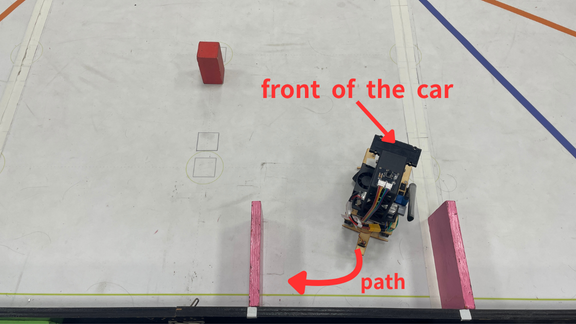
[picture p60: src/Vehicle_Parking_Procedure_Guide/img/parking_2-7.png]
<td width="50%"> </td>
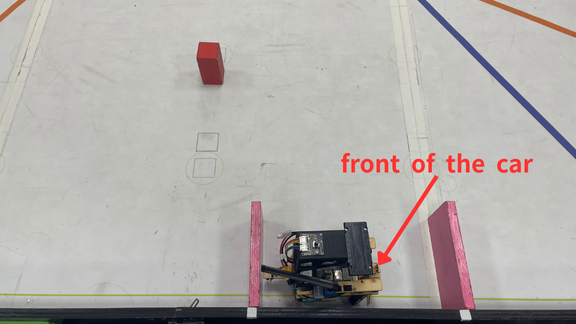
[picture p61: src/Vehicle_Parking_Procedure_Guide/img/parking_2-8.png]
<td width="50%"> </td>
</tr>

<tr>
<th colspan = 2>Video Documentation of the Autonomous Vehicle's Actual Run</th>
</tr>
<tr align=center>
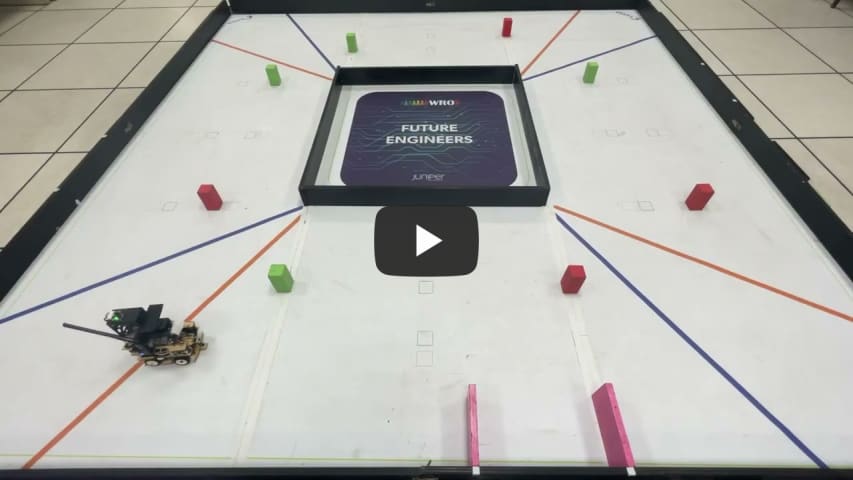
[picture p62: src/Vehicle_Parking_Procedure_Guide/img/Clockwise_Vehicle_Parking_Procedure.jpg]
Clockwise_Vehicle_Parking_Procedure
<td colspan = 2></td>
</tr>
</table>
</div>

# <div align="center">HOME[Return Home](../../)</div>

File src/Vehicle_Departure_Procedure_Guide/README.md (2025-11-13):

<div align="center">logo</div>

## <div align="center">Operational Procedure Guide for Vehicle Departure from the Parking Zone</div>
### Parking Lot Exit Overview
- #### Parking Lot Exit program
    1.  **System Startup and Direction Determination (Jetson Orin Nano Responsibility)**
         * When the vehicle starts, the **main control system (Jetson Orin Nano)** performs image recognition via the camera to first **determine the vehicle's default driving direction** (Counter-Clockwise or Clockwise). Subsequently, it identifies and locks onto the **color of the target track line**, which serves as the basis for the entire mission.

    2.  **Counter-Clockwise (CCW) Driving Logic**
        * **Upon detecting a Green Pillar:** The vehicle executes a **90-degree turn to the left** for a lane change, **driving forward to the inner side of the Green Pillar**. Subsequently, the vehicle **turns 90 degrees to the right** and **reverses to a predetermined position** (completing the inner lane change).
        * **Upon detecting a Red Pillar:** The vehicle **drives forward**, then **turns 90 degrees to the left**, **driving forward to the outer side of the Red Pillar**. Subsequently, the vehicle **reverses, turns 90 degrees to the right**, and **reverses to a predetermined position** (completing the outer lane change or avoidance).
        * **When no pillars are detected:** The system defaults the vehicle to **drive on the outer side of the lane**.

    3.  **Clockwise (CW) Driving Logic**
        * **Upon detecting a Green Pillar:** The vehicle executes a **90-degree turn to the right** for a lane change, **driving forward to the outer side of the Green Pillar**. Subsequently, the vehicle **turns 90 degrees to the left** and **drives forward to a predetermined position** (completing the outer lane change).
        * **Upon detecting a Red Pillar:** The vehicle executes a **90-degree turn to the right** for a lane change, **driving forward to the inner side of the Red Pillar**. Subsequently, the vehicle **turns 90 degrees to the left** and **drives forward to a predetermined position** (completing the inner lane change).
        * **When no pillars are detected:** The system defaults the vehicle to **drive on the outer side of the lane**.
- **Code running on the Raspberry Pi Pico W controller.**
    ```python
    # --- Execute rotation based on turn ---
    if turn == 1:
        print("Turning right") # Right turn message
        run_encoder_Auto(500, 45, 180) # Move with encoder and turn
    else:
        print("Turning left") # Left turn message
        run_encoder_Auto(1550, 45, -200) # Move with encoder and turn

    # --- mode 1: Color Decision ---
    mode = 1 # Change mode
    LAST_COLOR = 0 # Reset last color
    color = 0 # Reset color
    print(mode, color) # Debug print
    print('Waiting for color (M,<1..6>[,<...>] or JSON {"color":n})...') # Status message

    while mode == 1 and color == 0: # Loop until color is detected
        json_obj, m_tuple, got_stop = pump_uart(s) # Pump UART for data

        if json_obj:
            v = None # Value variable
            try:
                if "color" in json_obj:
                    v = int(json_obj["color"]) # Get color from JSON
                elif "c" in json_obj:
                    v = int(json_obj["c"]) # Get color from JSON (short key)
            except:
                v = None # Set to None on error
            if v is not None:
                if 1 <= v <= 6:
                    color = v # Set color
                    LAST_COLOR = color # Update last color
                    print("[JSON] color =", color) # Confirmation message
                    break # Break the loop
                else:
                    # Debug print: ignore out of range
                    if DEBUG: print("[IGNORE] JSON color out of range:", v) 
                    extract_magenta_from_json(json_obj) # Update magenta data

        if m_tuple:
            first = m_tuple[0] # First value of M command
            if 1 <= first <= 6:
                color = first # Set color
                LAST_COLOR = color # Update last color
                print("[M] color =", color, "raw:", m_tuple) # Confirmation message
                break # Break the loop
            else:
                # Debug print: ignore M packet
                if DEBUG: print("[IGNORE] M packet in mode1 (not color):", m_tuple) 
        if json_obj is None and m_tuple is None:
                    time.sleep(0.002) # Short sleep if no new data            
    # --- Color-based actions (Skipped for brevity, same as original) ---
    if color == 1:
        print("Color=1") # Status message
        run_encoder_Auto(1900, 70, 0) # Encoder move
        run_encoder_Auto(1500, 70, 180) # Encoder move
        run_encoder_Auto(1200, -45, 0) # Encoder move
    elif color == 2:
        print("Color=2") # Status message
        run_encoder_Auto(1700, 70, 0) # Encoder move
        run_encoder_Auto(1150, -50, -180) # Encoder move
    elif color == 3:
        print("Color=3") # Status message
        run_encoder_Auto(1700, 70, 0) # Encoder move
        run_encoder_Auto(1150, -50, -180) # Encoder move
    elif color == 4:
        print("Color=4") # Status message
        run_encoder_Auto(600, 40, 180) # Encoder move
        run_encoder_Auto(400, 50, 0) # Encoder move
        run_encoder_Auto(1100, 40, -180) # Encoder move
        run_encoder_Auto(800, 50, 0) # Encoder move
    elif color == 5:
        print("Color=5") # Status message
        run_encoder_Auto(600, 40, 180) # Encoder move
        run_encoder_Auto(2200, 60, 0) # Encoder move
        run_encoder_Auto(1400, 40, -180) # Encoder move
        run_encoder_Auto(500, 50, 0) # Encoder move
    elif color == 6:
        print("Color=6") # Status message
        run_encoder_Auto(600, 40, 180) # Encoder move
        run_encoder_Auto(400, 50, 0) # Encoder move
        run_encoder_Auto(1400, 40, -180) # Encoder move
        run_encoder_Auto(800, 50, 0) # Encoder move
    control_motor(0) # Stop motor
    set_servo_angle(0) # Center servo

    ```
## <div align=center>Counter-clockwise green departure process</div>
<div align=center>
<table>
<tr>
<th width="50%">Step-1: Preparing to turn left</th>
<th width="50%">Step-2: Start_reversing</th>
</tr><tr align=center>
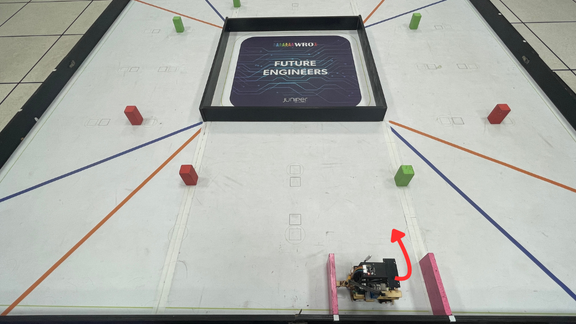
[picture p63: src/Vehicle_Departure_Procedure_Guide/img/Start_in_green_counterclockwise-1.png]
<td width="50%"></td>
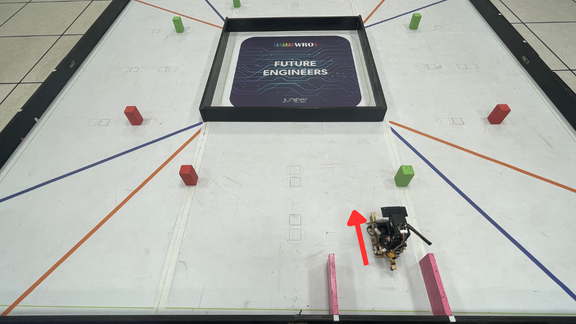
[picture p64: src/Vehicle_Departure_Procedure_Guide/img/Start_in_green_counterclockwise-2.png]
<td width="50%"></td>
</tr>

<tr>
<th width="50%">Step-3: Reparing to turn right</th>
<th width="50%">Step-4: Preparing to retreat</th>
</tr><tr align=center>
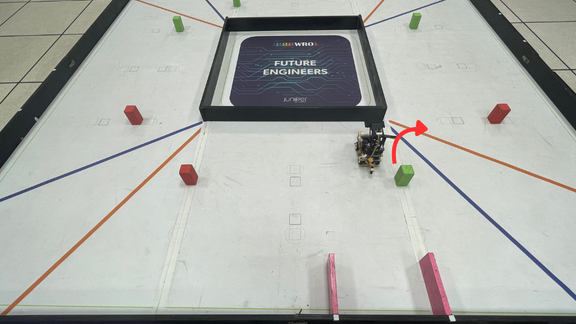
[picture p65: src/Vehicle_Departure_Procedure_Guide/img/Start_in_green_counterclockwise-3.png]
<td width="50%"></td>
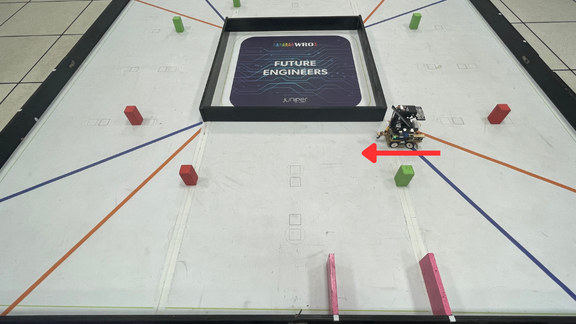
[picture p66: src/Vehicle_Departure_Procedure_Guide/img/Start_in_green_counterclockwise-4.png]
<td width="50%"></td>
</tr>

<tr>
<th>Step-5: Arrive at the designated location</th>
<th>Video Documentation of the Autonomous Vehicle's Actual Run</th>
</tr><tr align=center>
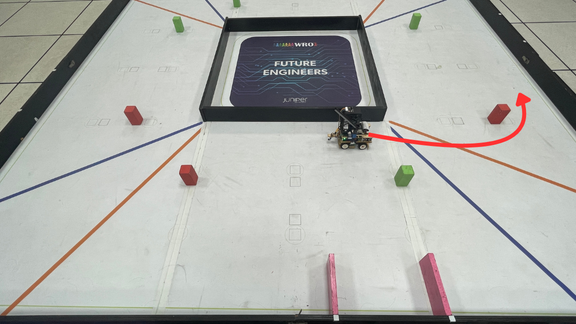
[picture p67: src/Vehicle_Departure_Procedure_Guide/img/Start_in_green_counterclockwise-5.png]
<td></td>
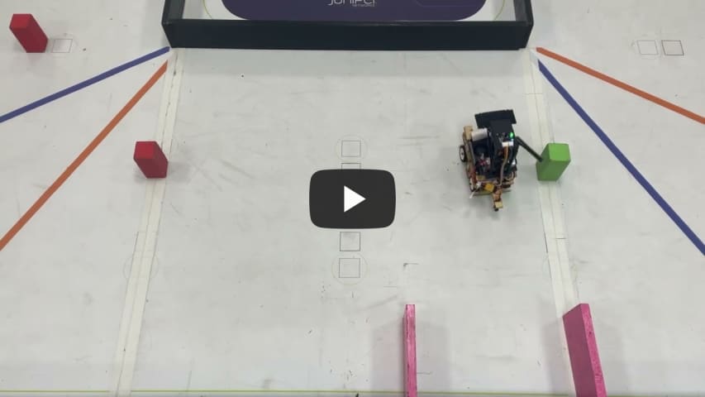
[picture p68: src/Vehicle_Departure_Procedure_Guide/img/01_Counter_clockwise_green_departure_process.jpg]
<td></td>
</tr>
</table>
</div>

## <div align="center">Counter-clockwise red departure process</div>
<div align=center>
<table>
<tr>
<th width="50%">Step-1: Preparing to turn left</th>
<th width="50%">Step-2: Start_reversing</th>
</tr><tr align=center>
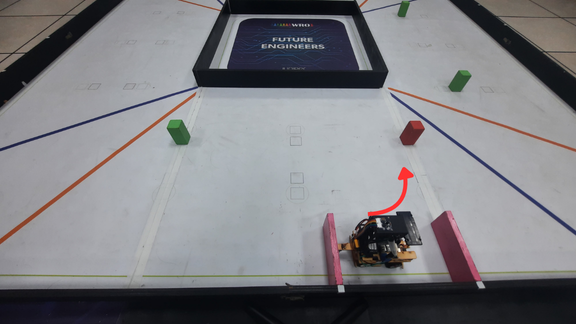
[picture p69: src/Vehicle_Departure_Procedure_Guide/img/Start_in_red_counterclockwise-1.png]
<td width="50%"></td>
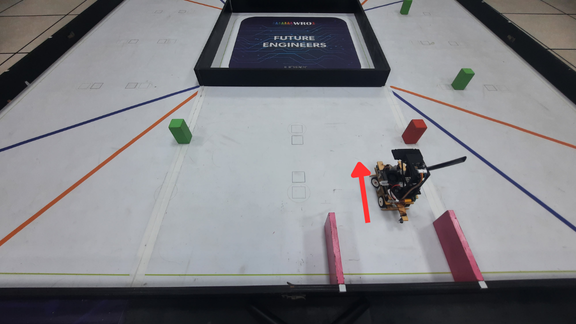
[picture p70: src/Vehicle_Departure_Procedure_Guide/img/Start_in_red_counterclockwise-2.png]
<td width="50%"></td>
</tr>

<tr>
<th width="50%">Step-3: Prepare to back up and turn left</th>
<th width="50%">Step-4: Arrive at the designated location</th>
</tr><tr align=center>
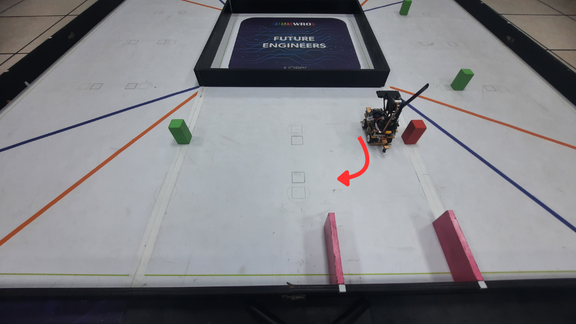
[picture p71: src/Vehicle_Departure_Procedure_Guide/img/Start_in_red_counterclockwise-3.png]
<td width="50%"></td>
<td width="50%"></td>
</tr>

<tr>
<th colspan=2>Video Documentation of the Autonomous Vehicle's Actual Run</th>
</tr>
<tr align=center>
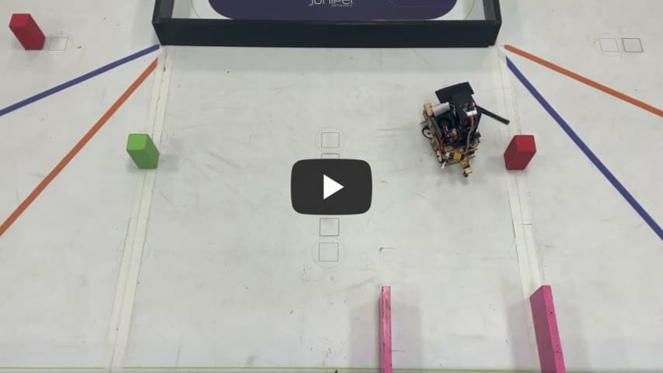
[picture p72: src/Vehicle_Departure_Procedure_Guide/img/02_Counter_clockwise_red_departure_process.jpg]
<td colspan=2></td>
</tr>
</table>
</div>

## <div align="center">Counter-clockwise, no color starting process</div>
<div align=center>
<table>
<tr>
<th width="50%">Step-1: Preparing to turn left</th>
<th width="50%">Step-2: Start_reversing</th>
</tr><tr align=center>
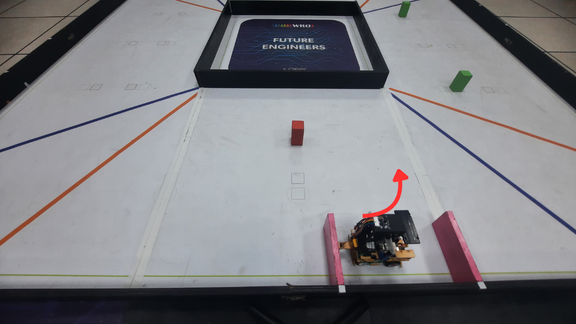
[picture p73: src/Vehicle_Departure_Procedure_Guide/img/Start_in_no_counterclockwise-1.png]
<td width="50%"></td>
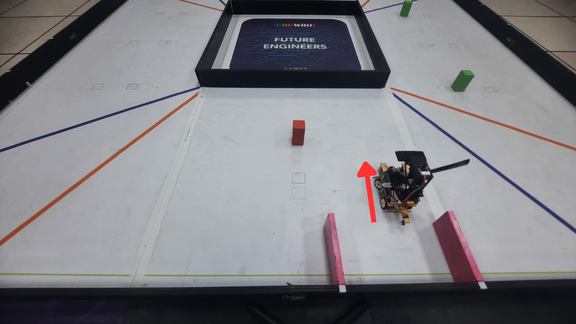
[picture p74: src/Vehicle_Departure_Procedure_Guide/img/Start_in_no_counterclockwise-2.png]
<td width="50%"></td>
</tr>

<tr>
<th width="50%">Step-3: Prepare to back up and turn left</th>
<th width="50%">Step-4: Arrive at the designated location</th>
</tr><tr align=center>
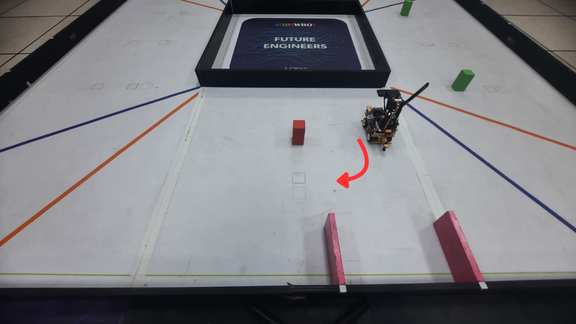
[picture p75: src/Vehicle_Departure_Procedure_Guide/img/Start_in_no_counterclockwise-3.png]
<td width="50%"></td>
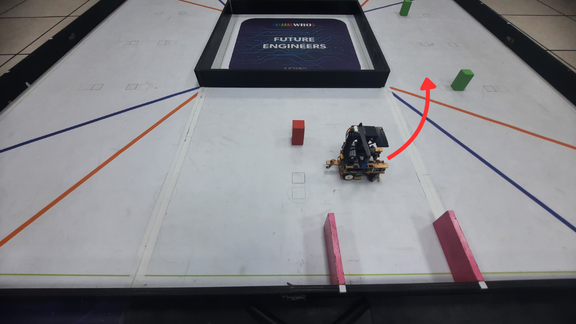
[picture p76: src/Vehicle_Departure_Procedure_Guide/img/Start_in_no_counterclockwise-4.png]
<td width="50%"></td>
</tr>

<tr>
<th colspan=2>Video Documentation of the Autonomous Vehicle's Actual Run</th>
</tr><tr align=center>
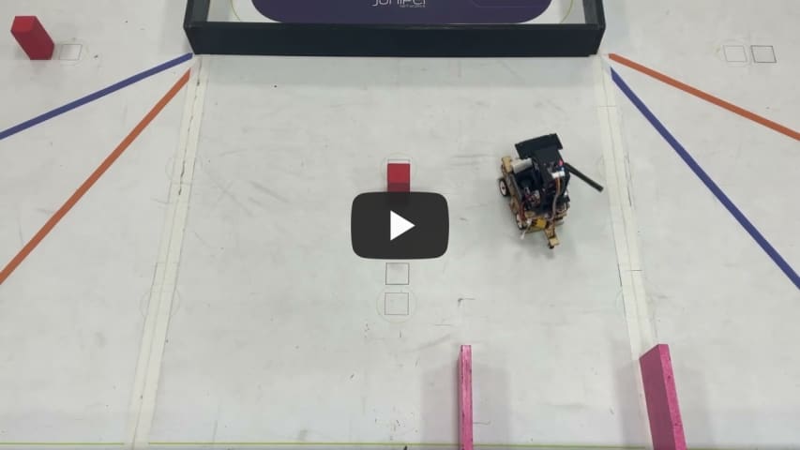
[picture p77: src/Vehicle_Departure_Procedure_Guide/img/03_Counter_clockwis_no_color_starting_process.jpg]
<td colspan=2></td>
</tr>
</table>
</div>

## <div align="center">Clockwise Green Departure Process</div>
<div align=center>
<table>
<tr>
<th width="50%">Step-1: Preparing to turn right</th>
<th width="50%">Step-2: Ready to move forward</th>
</tr><tr align=center>
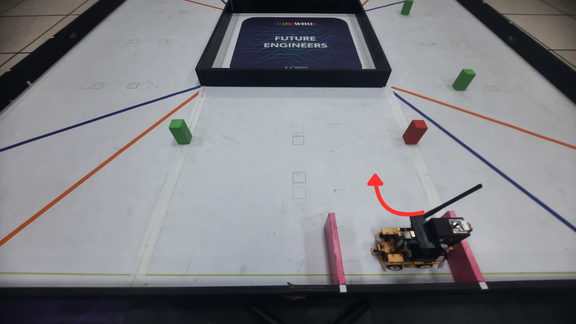
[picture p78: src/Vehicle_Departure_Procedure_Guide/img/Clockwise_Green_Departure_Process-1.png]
<td width="50%"></td>
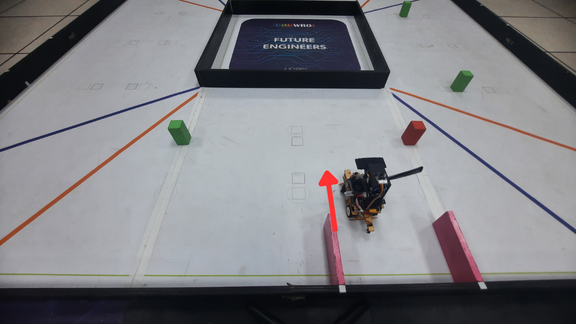
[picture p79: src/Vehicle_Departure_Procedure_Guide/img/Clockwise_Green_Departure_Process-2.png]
<td width="50%"></td>
</tr>

<tr>
<th width="50%">Step-3: Preparing to turn left</th>
<th width="50%">Step-4: Ready to move forward</th>
</tr><tr align=center>
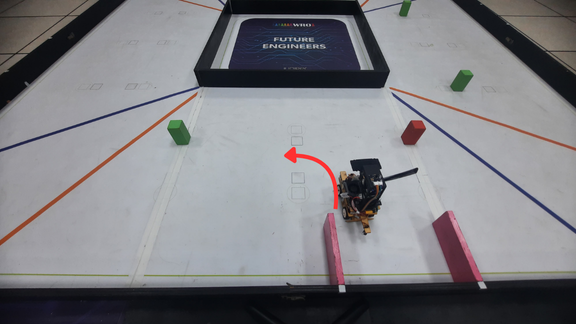
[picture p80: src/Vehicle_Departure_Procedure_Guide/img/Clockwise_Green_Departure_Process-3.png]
<td width="50%"></td>
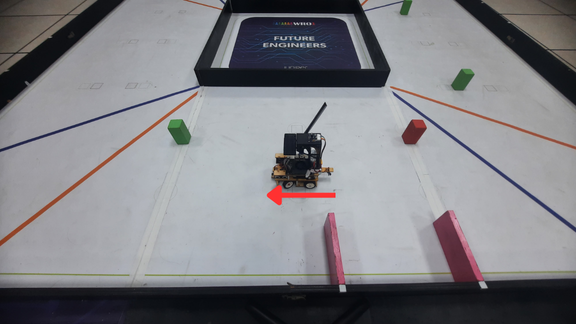
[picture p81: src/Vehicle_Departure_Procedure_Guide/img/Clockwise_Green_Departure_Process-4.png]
<td width="50%"></td>
</tr>

<tr>
<th width=50%>Step-5: Arrive at the designated location</th>
<th width=50%>Video Documentation of the Autonomous Vehicle's Actual Run</th>
</tr><tr align=center>
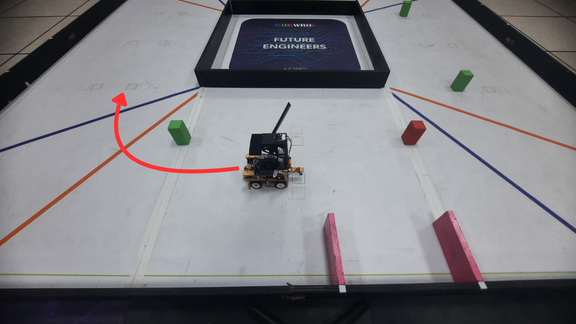
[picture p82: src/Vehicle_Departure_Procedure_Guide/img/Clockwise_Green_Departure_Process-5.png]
<td width=50%></td>
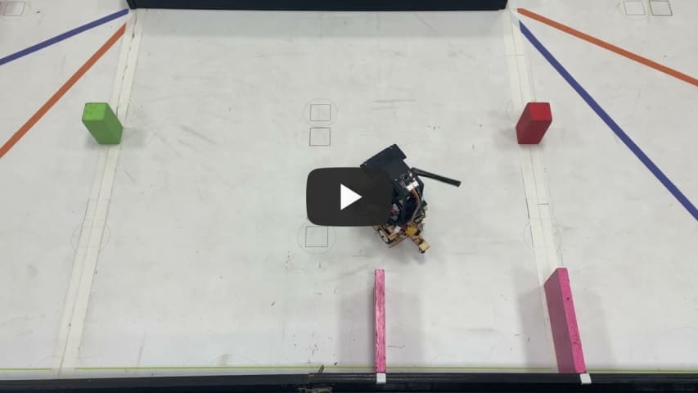
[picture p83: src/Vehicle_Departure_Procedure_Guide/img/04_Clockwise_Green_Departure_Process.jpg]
<td width=50%></td>
</tr>
</table>
</div>

## <div align="center">Clockwise Red Departure Process</div>
<div align=center>
<table>
<tr>
<th width="50%">Step-1: Preparing to turn right</th>
<th width="50%">Step-2: Ready to move forward</th>
</tr><tr align=center>
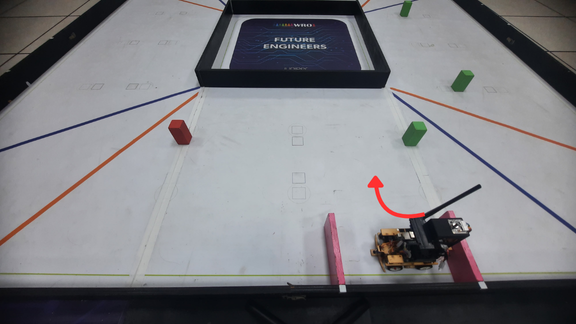
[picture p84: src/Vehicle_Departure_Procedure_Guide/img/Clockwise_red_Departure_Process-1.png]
<td width="50%"></td>
<td width="50%"></td>
</tr>

<tr>
<th width="50%">Step-3: Preparing to turn left</th>
<th width="50%">Step-4: Ready to move forward</th>
</tr><tr align=center>
<td width="50%"></td>
<td width="50%"></td>
</tr>

<tr>
<th>Step-5: Arrive at the designated location</th>
<th>Video Documentation of the Autonomous Vehicle's Actual Run</th>
</tr><tr align=center>
<td width="50%"></td>
<td width="50%"></td>
</tr>
</table>
</div>

## <div align="center">Clockwise green center departure process</div>
<div align=center>
<table>
<tr>
<th width="50%">Step-1: Preparing to turn right</th>
<th width="50%">Step-2: Preparing to turn left</th>
</tr><tr align=center>
<td width="50%"></td>
<td width="50%"></td>
</tr>

<tr>
<th width="50%">Step-3: Ready to move forward</th>
<th width="50%">Step-4: Arrive at the designated location</th>
</tr>
<tr>
<td width="50%"></td>
<td width="50%"></td>
</tr>

<tr>
<th colspan=2>Video Documentation of the Autonomous Vehicle's Actual Run</th>
</tr>
<tr align=center>
<td colspan=2></td>
</tr>
</table>
</div>

## <div align="center">Clockwise red center departure process</div>
<div align=center>
<table>
<tr>
<th width="50%">Step-1: Preparing to turn right</th>
<th width="50%">Step-2: Ready to move forward</th>
</tr><tr>
<td width="50%"></td>
<td width="50%"></td>
</tr

<tr>
<th width="50%">Step-3: Preparing to turn left</th>
<th width="50%">Step-4: Ready to move forward</th>
</tr><tr>
<td width="50%"></td>
<td width="50%"></td>
</tr>

<tr>
<th>Step-5: Arrive at the designated location</th>
<th>Video Documentation of the Autonomous Vehicle's Actual Run</th>
</tr>
<tr align=center>
<td></td>
<td></td>
</tr>

</table>
</div>

# <div align="center">HOME[Return Home](../../)</div>

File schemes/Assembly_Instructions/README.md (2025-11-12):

<div align="center">logo</div>

## <div align="center">Hardware Assembly Instructions & Wiring diagram</div>
- ### Hardware Configuration of Electronic Equipment 
  - The diagram below shows the placement of electronic equipment in the  Self-Driving-Cars.
  
    <div align="center">Components's Position</div>

- ### System Operation Process
    <div align="center">System Operation Process </div>
- This system utilizes the NVIDIA Jetson Orin Nano as its core controller, integrating a camera module to capture real-time imagery. The image data is processed efficiently using the **OpenCV library** to precisely identify critical elements on the race track, including **red and green obstacle pylons, the black boundary wall, the magenta parking boundary, and the blue and orange ground lines**. Furthermore, the system collects orientation data via the **I2C communication protocol** from a BNO055 Inertial Measurement Unit (IMU). This directional data is then used to calculate the precise heading, enabling the automated control objective of dynamically avoiding obstacles and boundaries, as well as accurately counting the number of laps completed.
- The NVIDIA Jetson Orin Nano, acting as the primary controller, generates final control signals after processing visual and sensor data. These signals are transmitted in real-time via the **UART communication protocol** to the Raspberry Pi Pico W I/O Controller, which is tasked with executing the subsequent low-level computation and physical actuation control.
- During the automated parking sequence, the Raspberry Pi Pico W I/O Controller functions as a crucial decision-making node. It not only receives high-level commands from the Jetson Orin Nano Master Controller but also simultaneously fuses data from various sensors for real-time calculation. This input includes distance measurements from dual HC-SR04 ultrasonic rangefinders located on both sides, as well as line-detection data from front and rear TCRT5000 infrared line sensors, all used to precisely govern the vehicle's maneuvering path.
- Serving as the I/O controller, the Raspberry Pi Pico W receives the vehicle motion control values transmitted from the Jetson Orin Nano master controller. The Pico W then performs further internal computation and signal conditioning before sending the resulting commands to the **front wheel servo motor (MG90S)**, thereby precisely controlling the steering angle to successfully complete the obstacle avoidance task.
- Concurrently, the Raspberry Pi Pico W, acting as the I/O controller, processes the vehicle movement control values received from the Jetson Orin Nano master controller. It then transmits this data to the **L293D Motor Driver** using **Pulse Width Modulation (PWM)** signals, which is necessary to control both the direction (forward/reverse) and the speed of the DC motor.

- ### Vehicle Body Structure Display Diagram
<div align="center">
<table>
  <tr>
      <th>Top View of the Overall Apparatus</th>
      <th>Top-Down View of the Vehicle's Mid-Level Structure</th>
      <th>Top View of Vehicle Chassis</th>
      <th>Bottom View of Vehicle Chassis</th>
  </tr>
  <tr align="center">
     <td>Top View of the Overall Apparatus </td>
     <td>Middle Layer Structure Top View</td>
     <td>Top View of Vehicle Chassis</td>
     <td>Bottom View of Vehicle Chassis</td>
  </tr>
</table>
</div>

- ### Circuit Board 
<div align="center">
<table>
  <tr align="center">
      <th> Overhead view of the main circuit board </th><th>Bottom View of the Main Circuit Board</th>
  </tr>
  <tr align="center">
     <td>  </td><td></td>
  </tr>
  <tr align="center">
      <th> Overhead view of the switch circuit board</th><th>Bottom view of the switch circuit board</th>
  </tr>
  <tr align=center>
    <td></td>
    <td></td>
</table>
</div>

- ### Overview of Important Parts List
  
  - #### NVIDIA® Jetson Orin Nano
  <table border=0 width="100%" >
      <tr>
      <td >
      
  __Specification:__ 

    - **AI Performance**  Up to **40 TOPS** (Sparse) or **20 TOPS** (Dense) 
    - **GPU**  **1024** NVIDIA **Ampere** Architecture **CUDA Cores** + - - **32** **Tensor Cores** 
    - **CPU**  **6-core** Arm Cortex-A78AE v8.2 64-bit CPU (up to **1.5 GHz**) 
    - **Memory (RAM)**  **8GB** 128-bit **LPDDR5** (Memory bandwidth up to **68 GB/s**) 
    - **Video Encoder**  1x 4K @ 30fps, 2x 4K @ 30fps, 5x 1080p @ 60fps, etc. (H.265) 
    - **Video Decoder**  1x 4K @ 60fps, 2x 4K @ 30fps, 5x 1080p @ 60fps, etc. (H.265) 
    - **Camera Interface**  **8-lane MIPI CSI-2** D-PHY 2.1 (Supports up to 4 physical cameras) 
    - **PCIe**  1x x4 + 3x x1 (PCIe Gen3) 
    - **Ports**  4x USB 3.2 Gen2, 1x USB Type-C (Power/Debug), Gigabit Ethernet 
    - **Display Output**  1x DP 1.2 (+MST) or eDP 1.4/HDMI 1.4 
    - **Storage**  Supports external NVMe SSD (on Developer Kit) and MicroSD card 
    - **Input Voltage**  DC **9V-20V** 
  <br></br>

  __Uses in Competition:__ 
    - Responsible for receiving image data from the camera module, performing image recognition via OpenCV, and sending the recognition results to the Raspberry Pi Pico W for further processing.

    <br></br>
    __Purchase URL:<a href="https://www.nvidia.com/zh-tw/autonomous-machines/embedded-systems/jetson-orin/nano-super-developer-kit/" target="_blank">NVIDIA® Jetson Orin Nano</a>__
    </td>
    <td>
    Jjetson_orin_nano   
    </td>
    </tr>
    </table>

  - #### Raspberry Pi Pico w
  <table border=0 width="100%" >
      <tr>
      <td> 

  __Specifications:__  

  * **Processor (CPU):** Raspberry Pi RP2040 chip (dual-core ARM Cortex-M0+)
  * **Clock Speed:** Up to 133 MHz
  * **Memory (SRAM):** 264 KB
  * **Flash Storage:** 2 MB external QSPI Flash
  * **Wireless Connectivity:** 2.4GHz Wi-Fi (802.11 b/g/n) – powered by Infineon CYW43439 chip
  * **Bluetooth:** Not supported (the CYW43439 includes Bluetooth hardware, but it is not enabled on the Pico W)
  * **GPIO Pins:** 26 usable GPIO pins (3.3V logic)
  * **ADC Analog Inputs:** 3 channels (12-bit resolution)
  * **PWM Output:** Multiple channels available
  * **Communication Interfaces:** I²C, SPI, UART, USB 1.1 (Device/Host)
  * **Power Supply:** 1.8–5.5V (via USB or external power input)
 <br></br>

  __Uses in Competition：__
  - This Low-Level Controller (LLC) is responsible for data acquisition, integration, and control execution. Its functions include:
    - Real-time acquisition of environmental distance data from all ultrasonic distance sensors and the TCRT5000 Infrared Sensor.
    - Receiving decisional control commands transmitted from the High-Level Controller (HLC), the NVIDIA® Jetson Orin Nano.
    - Integrating and computing the acquired sensor data and control commands to generate precise actuation signals.
    - Driving and controlling the front-wheel steering servo motor and the rear-drive DC motor to achieve precise vehicle steering and locomotion control.

 <br></br>

  __Purchase URL:[Raspberry Pi Pico w](https://piepie.com.tw/product/raspberry-pi-pico-w)__
    </td>
       <td >
    MG513-P30   
      </td>
      </tr>
    </table>

  - #### MG513-P30 Rear-Drive DC Motor
  <table border=0 width="100%" >
      <tr>
      <td> 

  __Specifications:__  
   - No-load Speed: 366 rpm
   - Reduction Ratio: 1:30
   - Operating Voltage: 6 - 12V

 <br></br>

  __Uses in Competition：__
  - Responsible for receiving control signals from the motor driver controller L293D to adjust the vehicle's forward and reverse movements and control the rear wheel speed.
 <br></br>

  __Purchase URL:[MG513-P30 336RPM DC reduction motor](https://www.amazon.com/-/zh_TW/MG513-12V-%E6%B8%9B%E9%80%9F%E9%BD%92%E8%BC%AA%E9%A6%AC%E9%81%94%E7%B7%A8%E7%A2%BC%E5%99%A8%E4%BB%A3%E7%A2%BC%E9%80%9F%E5%BA%A6%E6%B8%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)__
    </td>
       <td >
    MG513-P30   
      </td>
      </tr>
    </table>

  - #### MG90S Front Steering Mechanism by Servo Motor
  <table border=0 width="100%" >
      <tr>
      <td> 

  __Specifications:__
   - Controllable Rotation Angle: 0-180°  
   - Maximum Torque: 2.0 kg/cm (at 4.8V)  
   - Fastest Rotation Speed: 0.11 seconds (at 4.8V)  
   - Operating Voltage: 4.8V - 7.2V  
 <br></br>

  __Uses in Competition：__
   - Responsible for receiving control values from the Raspberry Pi Pico to adjust the front wheel steering angle, enabling precise steering during driving.
 <br></br>

  __Purchase URL:<a href="https://www.amazon.com/-/zh_TW/dp/B0BFQLNDPM" target="_blank">MG90s servo motor</a>__
    </td>
       <td >
    MG90S servo motor  
       </td>
      </tr>
    </table>

  - #### Dual H-bridge DC motor driver IC - L293D

  <table border=0 width="100%" >
      <tr>
      <td>  

  __Specifications:__ 
   - 293D is a dual H-bridge DC motor driver IC that can be used to control two DC motors.
   - Wide operating voltage range: 4.5V to 36V.
   - Output current: 600 mA (continuous) and 1.2 A (peak) per channel.
   - Output voltage range: 3 V to 36 V.
 <br></br>

  __Uses in Competition：__  
   - Primarily responsible for driving the MG513 geared DC motor to control the vehicle’s forward and reverse movement, as well as the motor’s speed.
 <br></br>

  __Purchase URL:<a href="https://atceiling.blogspot.com/2019/08/arduino54l293d.html" target="_blank">L293D</a>__
    </td>
      <td>
    L293d motor controler  
      </td>
      </tr>
    </table>

  - #### Li-Polymer 3S Battery
  <table border=0 width="100%" >
      <tr>
      <td> 

  __Specifications:__
   - Maximum Current: 45.5A  
   - Net Weight: Approximately 107g  
   - Rated Voltage: 11.1V
   <br></br>
  
  __Uses in Competition：__  
   - Supply power to the vehicle for use.  
 <br></br>

  __Purchase URL:<a href="https://shopee.tw/product/17393576/2036942264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" target="_blank">Li-Polymer 3S Battery</a>__
    </td>
    <td>
    Li-Polymer 3S Battery  
    </td>
    </tr>
    </table>

  - #### Micro switch
  <table border=0 width=100% >
      <tr>
      <td>
   
  __Specifications:__ 
   - Operating Voltage: 3.3V - 5.0V  
   - Number of Pins: 3  
   - Output Signal: Digital  
 <br></br>

  __Uses in Competition：__
   - Control the vehicle's start and drive switch.
 <br></br>

  __Purchase URL:<a href="https://www.amazon.com/-/zh_TW/PLKXSEYUJ/dp/B0D4HZFM6S" target="_blank">Micro switch</a>__
    </td>
      <td>
    Button(TACK-SW)   
      </td>
      </tr>
    </table>

  - #### High Current 5A Constant Voltage Constant Current Buck Power Supply Module ADIO-DC36V5A

  <table border=0 width=100% >
      <tr>
      <td> 

  __Specifications:__ 
   - Input Voltage Range: 4 - 38V
   - Output Voltage Range: 1.25 - 36V, continuously adjustable
   - Output Current Range: Adjustable, maximum of 5A

 <br></br>

  __Uses in Competition：__  
   - Primarily responsible for stepping down the battery voltage from 11.1V to 5V to provide various stable voltages needed for vehicle operation.
 <br></br>

  __Purchase URL:<a href="https://shop.cpu.com.tw/product/57434/info/" target="_blank">ADIO-DC36V5A</a>__
    </td>
      <td>
    ADIO-DC36V5A   
      </td>
      </tr>
    </table>

  - #### SONY IMX477 Camera Module
  <table border=0 width="100%" >
      <tr>
      <td>

  __Specifications:__
   - Viewing Angle: 160 degrees
   - pixels: 4056 x 3040
   - Maximum aperture: F2.0
   - Focal length: 7.9mm
   - Interface: CSI (Camera Serial Interface)
   - Operating Voltag：3.3V
 <br></br>

  __Uses in Competition：__  
   - Responsible for capturing images and transmitting them to the Jetson Nano for image recognition to detect the presence of obstacles or boundary walls.
 <br></br>

  __Purchase URL:<a href="https://shopee.tw/%E7%8F%BE%E8%B2%A8-SONY-IMX477-%E6%94%9D%E5%BD%B1%E9%8F%A1%E9%A0%AD%E6%A8%A1%E7%B5%84-1230%E8%90%AC%E5%83%8F%E7%B4%A0-160%C2%B0%E5%BB%A3%E8%A7%92-%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" target="_blank">SONY IMX477</a>__
    </td>
       <td >
    SONY IMX477 Camera Module    
       </td>
      </tr>
    </table>

  - #### BNO055 Gyroscope orientation sensor
  <table border=0 width="100%" >
      <tr>
      <td> 

  __Specifications:__
   - 9-Axis Sensing: Includes accelerometer, gyroscope, and magnetometer for motion and orientation detection
   - Operating Voltage: 3.6V - 5V
   - Interface: Supports both I²C and UART, making it compatible with various devices
   - Orientation Data: Provides direct angle data for accurate positioning
  <br></br>

  __Uses in Competition：__  
   - Responsible for detecting the vehicle's current orientation values, which are provided to the  Jetson Nano controller for processing and decision-making.
 <br></br>

  __Purchase URL:<a href="https://www.remisys.com.tw/product-page/bno055-absolute-orientation-sensor" target="_blank">BNO055</a>__
    </td>
       <td >
    SBNO055 Gyroscope orientation sensor    
       </td>
      </tr>
    </table>

  - #### HC-SR04 ultrasonic distance sensor
  <table border=0 width="100%" >
      <tr>
      <td> 

  __Specifications:__
   - Measuring Range: 2 cm to 400 cm, capable of detecting objects within a distance of 2 cm to 4 meters.
   - Measurement Accuracy: Approximately 3 mm, with a margin of error around ±3 mm.
   - Operating Voltage: 5V, powered by direct current.
   - Ultrasonic Frequency: 40kHz, measuring distance by emitting a 40kHz ultrasonic signal.
   - Transmission Interface: Includes Trig and Echo pins, where Trig sends out the ultrasonic signal and Echo receives the reflected signal to calculate the distance.
 <br></br>

  __Uses in Competition：__  
   - The core function of this system is to acquire real-time measurement data from two sets of HC-SR04 ultrasonic distance sensors. Subsequently, this distance data is transmitted to the Raspberry Pi Pico W microcontroller for computational and decision-making processes, with the ultimate goal of achieving precise control over the vehicle's driving direction.
   <br></br>

  __Purchase URL:<a href="https://robotkingdom.com.tw/product/hc-sr04p-ultrasonic-ranger/" target="_blank">HC-SR04</a>__
    </td>
       <td >
    HC-SR04 ultrasonic distance sensor    
       </td>
      </tr>
    </table>

  - #### TCRT5000 Infrared Sensor

  <table>
      <tr>
      <td>

  __Specifications:__ 
  - Measuring Range: 0 to 1.5 centimeters (cm)
  - Operating Voltage: 3.3 Volts (V) to 5 Volts (V)
 <br></br>

  __Uses in Competition：__  
   - The primary function of this system is to accurately measure the distance between the vehicle and the field boundary (or surrounding walls). The acquired data is then transmitted to the Raspberry Pi Pico W for efficient computation and decision-making processing, with the ultimate goal of achieving precise navigation and control over the vehicle's direction of travel.

  <br></br>
    __Purchase URL:<a href="https://www.icshop.com.tw/products/368030501146" target="_blank">TCRT5000</a>__
        </td>
        <td>
          
        </td>
      </tr>
    </table>

# <div align="center">HOME[Return Home](../../)</div>

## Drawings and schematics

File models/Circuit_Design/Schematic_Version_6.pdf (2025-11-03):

A | A

1

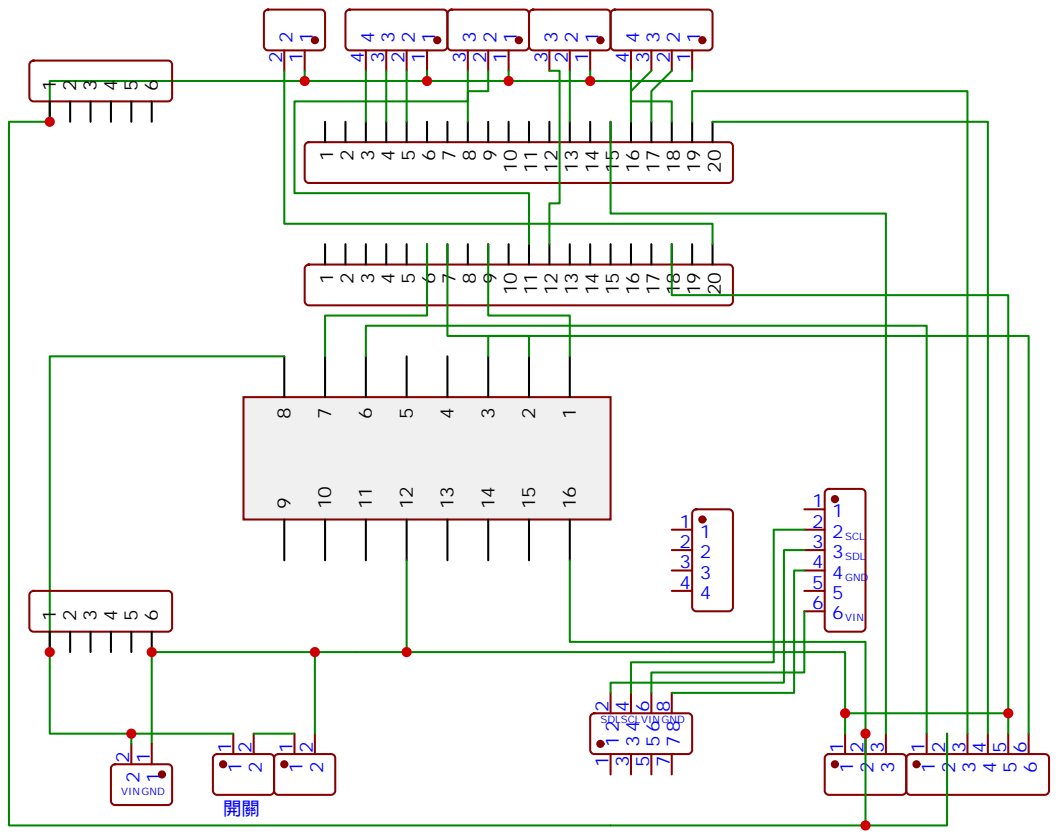
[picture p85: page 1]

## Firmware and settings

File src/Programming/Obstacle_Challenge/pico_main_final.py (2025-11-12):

from machine import Pin, PWM, ADC, time_pulse_us, UART
import time, uos, ujson as json

UART_ID = 1      # Usually use UART 1 (or 0)
TX_PIN = 8       # Pico W GPIO Pin for TX (Connects to Jetson's RX)
RX_PIN = 9       # Pico W GPIO Pin for RX (Connects to Jetson's TX)
BAUD_RATE = 115200 # Recommend using a higher speed, please ensure Jetson's setting is consistent
DEBUG = True # Set to False if you want it to be quieter
MECH_SIGN      = +1 # Mechanical sign (for steering direction)
CENTER_TRIM_DEG  = 0 # Center trim in degrees
SERVO_MIN_US     = 1000 # Minimum pulse width in microseconds
SERVO_MAX_US     = 2000 # Maximum pulse width in microseconds
led = Pin("LED", Pin.OUT) # Onboard LED pin
A0PIN = 26  # Use ADC0, corresponding to GPIO26
A1PIN = 27  # Use ADC1, corresponding to GPIO27
A0 = ADC(Pin(A0PIN)) # Initialize ADC object for A0
A1 = ADC(Pin(A1PIN)) # Initialize ADC object for A1
TRIG_PIN1 = 2 # Trigger pin for ultrasonic sensor 1
ECHO_PIN1 = 3 # Echo pin for ultrasonic sensor 1
TRIG_PIN2 = 12 # Trigger pin for ultrasonic sensor 2
ECHO_PIN2 = 13 # Echo pin for ultrasonic sensor 2
trig1 = Pin(TRIG_PIN1, Pin.OUT) # Initialize trig1 as an output pin
echo1 = Pin(ECHO_PIN1, Pin.IN) # Initialize echo1 as an input pin
trig2 = Pin(TRIG_PIN2, Pin.OUT) # Initialize trig2 as an output pin
echo2 = Pin(ECHO_PIN2, Pin.IN) # Initialize echo2 as an input pin
servo_pin   = PWM(Pin(4), freq=50) # Initialize PWM for servo on GP4 at 50Hz
motor_in1   = Pin(21, Pin.OUT) # Motor driver input 1 on GP21
motor_in2   = Pin(20, Pin.OUT) # Motor driver input 2 on GP20
motor_pwm   = PWM(Pin(22), freq=1000) # Initialize PWM for motor speed on GP22 at 1000Hz
encoder_pin_A, encoder_pin_B = Pin(0, Pin.IN), Pin(1, Pin.IN) # Encoder pins A and B
encoder_count, last_state_A  = 0, encoder_pin_A.value() # Initialize encoder count and last state

RXBUF = ""           # Buffer for parsing JSON / M / STOP messages
LAST_COLOR = 0       # Stores any color received early in any state
magArea, magCX, magCY = 0, -1, -1 # Area, center X, and center Y of magenta object

UART_RECV_TIMEOUT = 0 

USE_ACTIVE_BRAKE = True # Flag to use active braking

def motor_brake():
    motor_in1.high() # Set motor direction pin 1 to HIGH
    motor_in2.high() # Set motor direction pin 2 to HIGH
    try:
        motor_pwm.duty_u16(65535) # Set PWM duty cycle to maximum for full brake
    except:
        pass # Ignore errors if PWM fails

def motor_coast():
    try:
        motor_pwm.duty_u16(0) # Set PWM duty cycle to zero
    except:
        pass # Ignore errors if PWM fails
    motor_in1.low() # Set motor direction pin 1 to LOW
    motor_in2.low() # Set motor direction pin 2 to LOW

def _clamp(v, lo, hi):
    return lo if v < lo else (hi if v > hi else v) # Clamps a value 'v' between 'lo' and 'hi'

def _map_servo_us(abs_deg_0_180):
    abs_deg_0_180 = _clamp(int(abs_deg_0_180), 0, 180) # Clamp angle between 0 and 180 degrees
    return SERVO_MIN_US + (SERVO_MAX_US - SERVO_MIN_US) * abs_deg_0_180 / 180.0 # Map angle to pulse width (us)

def set_servo_rel_deg(rel_deg):
    try:
        rel = int(rel_deg) # Convert relative angle to integer
    except:
        rel = 0 # Default to 0 if conversion fails
    rel = _clamp(rel, -180, 180) # Clamp relative angle
    abs_deg = 90 + CENTER_TRIM_DEG + MECH_SIGN * rel # Calculate absolute angle (0-180)
    abs_deg = _clamp(int(abs_deg), 0, 180) # Clamp absolute angle
    duty_us = _map_servo_us(abs_deg) # Map absolute angle to pulse width in us
    servo_pin.duty_u16(int(duty_us * 65535 / 20000)) # Set PWM duty cycle (u16 based on 20ms period)

def set_servo_angle(angle_in):
    set_servo_rel_deg(angle_in) # Public function to set servo angle

def control_motor(speed):
    try:
        sp = int(speed) # Convert speed to integer
    except:
        sp = 0 # Default to 0 if conversion fails
    sp = _clamp(sp, -100, 100) # Clamp speed between -100 (reverse) and 100 (forward)

    if sp == 0:
        if USE_ACTIVE_BRAKE:
            motor_brake() # Apply active brake
        else:
            motor_coast() # Coast the motor
        return # Exit the function if speed is 0

    try:
        motor_pwm.duty_u16(0) # Temporarily set PWM to 0 before changing direction
    except:
        pass # Ignore errors

    if sp > 0:
        motor_in1.high(); motor_in2.low() # Set direction for forward
    else:
        motor_in1.low(); motor_in2.high() # Set direction for reverse

    try:
        motor_pwm.duty_u16(int(abs(sp) * 65535 / 100)) # Set PWM duty cycle based on absolute speed
    except:
        pass # Ignore errors

def encoder_interrupt(pin):
    global encoder_count, last_state_A # Access global variables
    state_a = encoder_pin_A.value() # Read current state of pin A
    if state_a != last_state_A: # Check if pin A state has changed (rising or falling edge)
        state_b = encoder_pin_B.value() # Read current state of pin B
        encoder_count += 1 if state_a == state_b else -1 # Increment/decrement count based on direction
        last_state_A = state_a # Update last state of pin A

encoder_pin_A.irq(trigger=Pin.IRQ_RISING | Pin.IRQ_FALLING, handler=encoder_interrupt) # Attach interrupt handler to pin A

def run_encoder_Auto(motor_angle, speed, steer_deg):
    global encoder_count # Access global encoder count
    encoder_count = 0 # Reset encoder count
    set_servo_angle(steer_deg) # Set the steering angle
    while abs(encoder_count) < motor_angle: # Loop until target encoder count is reached
        control_motor(speed) # Control the motor speed
        time.sleep(0.01) # Small delay for control loop
    control_motor(0) # Stop the motor
    set_servo_angle(0) # Reset servo angle to center

def measure_distance(trig, echo):
    trig.value(0); time.sleep_us(2) # Set trigger low for 2us
    trig.value(1); time.sleep_us(10); trig.value(0) # Send 10us pulse
    duration = time_pulse_us(echo, 1) # Measure the pulse width on the echo pin
    if duration <= 0:
        return 9999 # Return a large value if measurement fails
    distance = (duration / 2) * 0.0343 # Calculate distance in cm (speed of sound: 0.0343 cm/us)
    return distance # Return the measured distance

def connect_uart():
    """Initialize and connect UART"""
    try:
        uart = UART(UART_ID, baudrate=BAUD_RATE, tx=Pin(TX_PIN), rx=Pin(RX_PIN), timeout=0)
        if DEBUG:
            print(f"UART {UART_ID} Initialized (TX:GP{TX_PIN}, RX:GP{RX_PIN}, Baud:{BAUD_RATE})") # Debug print: UART setup success
        return uart # Return the UART object
    except Exception as e:
        print(f"UART connect failed: {e}") # Print error if UART initialization fails
        raise OSError("UART Init failed") # Raise OSError to indicate failure
        
def uart_send(uart_obj, text):
    """Send text over UART"""
    try:
        uart_obj.write(text.encode('utf-8')) # Encode text to bytes and write to UART
    except Exception as e:
        if DEBUG:
            print(f"UART send error: {e}") # Debug print: UART send error

def uart_recv_chunk(uart_obj, timeout=UART_RECV_TIMEOUT):
    """Non-blocking read of data chunk from UART"""
    try:
        if uart_obj.any(): # Check if any data is available
            received = uart_obj.read() # Read all available bytes
            if received:
                if DEBUG:
                    print(f"[Pico W] Received raw bytes: {received}") # ★ Debug: Show raw received data
                return received.decode('utf-8') # Decode to string and return
    except Exception as e:
        if DEBUG:
            print(f"UART read error: {e}") # Debug print: UART read error
    return None # Return None if no data or error

def parse_json_msg(s):
    try:
        obj = json.loads(s) # Attempt to parse JSON string
        return obj if isinstance(obj, dict) else None # Return dictionary if successful, else None
    except Exception:
        return None # Return None on parsing error

def parse_m_line(s):
    if not s.startswith("M,"): # Check for "M," prefix
        return None # Not an M command
    parts = s.strip().split(",") # Split the line by comma
    if len(parts) >= 2: # Must have at least two parts
        try:
            val1 = int(parts[1]) # First value (signal or angle)
            val2 = int(parts[2]) if len(parts) >= 3 else 0 # Second value (speed, default to 0)
            
            # Assume val1 is angle/signal, val2 is speed
            if len(parts) == 2: # M,<signal>
                 # If it's a start/color signal (1~6), speed is 0
                 if 1 <= val1 <= 6:
                     return _clamp(val1, 1, 6), 0 # Return (signal, 0)
                 # If not a signal, treat as M,<angle>,0
                 return _clamp(val1, -180, 180), 0
                 
            # M,<angle>,<speed>
            return _clamp(val1, -180, 180), _clamp(val2, -100, 100) # Return (angle, speed)
            
        except Exception as e:
            if DEBUG: print(f"M parse error: {e}, raw: {s}") # Debug print: M parsing error
            return None # Return None on parsing error
    return None # Return None if not enough parts


def extract_magenta_from_json(obj):
    global magArea, magCX, magCY # Access global magenta data
    if not obj:
        return # Exit if object is None
    try:
        if "magArea" in obj: magArea = int(obj["magArea"]) # Update magenta area
        if "magCX"   in obj: magCX   = int(obj["magCX"]) # Update magenta center X
        if "magCY"   in obj: magCY   = int(obj["magCY"]) # Update magenta center Y
    except:
        pass # Ignore errors during type conversion

def pump_uart(uart_obj):
    """
    Non-blocking read from UART, parsing JSON / M / STOP commands.
    Returns (json_obj, m_tuple, got_stop)
    """
    global RXBUF # Access global receive buffer
    json_obj = None # Initialize parsed JSON object
    m_tuple = None # Initialize parsed M command tuple
    got_stop = False # Initialize STOP flag

    msg = uart_recv_chunk(uart_obj, timeout=UART_RECV_TIMEOUT) # Get raw data chunk
    if msg:
        RXBUF += msg # Append to global buffer
        
    if len(RXBUF) > 4096:
        RXBUF = RXBUF[-1024:] # Truncate buffer to prevent overflow

    idx_stop = RXBUF.find("STOP") # Find "STOP" in buffer
    if idx_stop != -1:
        end = idx_stop + 4 # End of "STOP"
        if end < len(RXBUF) and RXBUF[end:end+1] == "\n": # Check for newline after STOP
            end += 1 # Include newline if present
        RXBUF = RXBUF[:idx_stop] + RXBUF[end:] # Remove "STOP" and any following newline from buffer
        got_stop = True # Set stop flag
        if DEBUG:
            print("[PICO] GOT STOP SIGNAL") # Debug print: STOP received
            
    for _ in range(12): # Limit parsing iterations per call
        if not RXBUF:
            break # Break if buffer is empty

        idx_json = RXBUF.find("{") # Find start of JSON
        idx_m    = RXBUF.find("M,") # Find start of M command

        if idx_json == -1 and idx_m == -1:
            if RXBUF.strip() and not (RXBUF.startswith("M,") or RXBUF.startswith("{")):
                if DEBUG: print(f"[PICO] Cleared junk: {RXBUF.strip()[:10]}...") # Debug print: cleared junk
                RXBUF = "" # Clear junk data
            break # No command starters found

        if idx_json != -1 and (idx_m == -1 or idx_json < idx_m):
            # Process JSON (Telemetry data from Jetson, including magenta info)
            end = RXBUF.find("}", idx_json) # Find end of JSON
            if end == -1:
                break # JSON incomplete, break and wait for more data
            candidate = RXBUF[idx_json:end+1] # Extract the JSON candidate string
            next_idx = end + 1 # Index after '}'
            if next_idx < len(RXBUF) and RXBUF[next_idx] == "\n":
                next_idx += 1 # Skip newline if present
            RXBUF = RXBUF[next_idx:] # Update buffer
            
            obj = parse_json_msg(candidate) # Parse the JSON message
            
            if obj:
                json_obj = obj # Store the parsed object
                if DEBUG: print("PARSED_JSON:", obj) # Debug print: parsed JSON
                extract_magenta_from_json(obj) # Extract magenta data
                continue # Continue to check for next command
            else:
                continue # JSON parsing failed, continue to check next part of buffer
        else:
            # Process M command (Control command or signal from Jetson)
            nl = RXBUF.find("\n", idx_m) # Find newline after M command
            if nl == -1:
                # If M command has no newline, process the part starting with M and truncate
                # This handles cases where 'M,angle,speed\n' is received as 'M,angle,speed'
                candidate = RXBUF[idx_m:].strip() # Get remaining part
                RXBUF = RXBUF[:idx_m] # Clear M part (will likely be re-appended if partial)
            else:
                candidate = RXBUF[idx_m:nl].strip() # Extract the M command line
                RXBUF = RXBUF[nl+1:] # Update buffer by skipping the M command and newline

            parsed = parse_m_line(candidate) # Parse the M command
            if parsed:
                m_tuple = parsed # Store the parsed M tuple
                if DEBUG: print("PARSED_M:", m_tuple, "RAW=", candidate) # Debug print: parsed M
                
                # ★ Execute control command
                # The first value in M format can be a signal or an angle
                if len(m_tuple) == 2:
                    val1, speed = m_tuple # Unpack tuple
                    if 1 <= val1 <= 6:
                        # This is a signal (color or start signal)
                        pass # Signal processing is usually handled outside
                    else:
                        # This is a control command (angle, speed)
                        set_servo_angle(val1) # Set servo angle
                        control_motor(speed) # Control motor speed
                
                continue # Continue to check for next command
            else:
                continue # M parsing failed, continue to check next part of buffer

    return json_obj, m_tuple, got_stop # Return results

# =============== Main ===============
def run():
    global LAST_COLOR, encoder_count, mag_area, mag_cx, mag_cy # Access global variables
    motor_in1.off() # Ensure motor direction pin 1 is off
    motor_in2.off() # Ensure motor direction pin 2 is off
    control_motor(0) # Stop motor
    set_servo_angle(0) # Center servo
    led.off() # Turn off LED
    
    # Initialize UART
    try:
        uart_port = connect_uart() # Connect to UART
    except OSError:
        # If UART fails during initial connect, don't enter the main loop immediately
        time.sleep(1)
        return

    while True:
        try:
            print("UART Port Ready. Waiting for commands...") # Status message
            s = uart_port # Alias for UART object
            
            print("Pico W initialized.") # Status message
            
            # Send Pico Ready message to Jetson
            uart_send(s, json.dumps({"from":"pico","status":"ready"}) + "\n") # Send ready signal as JSON
            print("[Pico W] Sent ready signal to Jetson.") # Confirmation message
            
            led.on() # Turn on LED to indicate ready state

            mode = 0 # Current mode of operation
            turn = 0 # Starting direction (turn)
            color = 0 # Detected color signal
            count = 0 # General counter
            yaw = 0 # Yaw angle from Jetson (e.g., IMU)
            angle_from_jetson = 0 # Steering angle from Jetson (if M command not used)
            speed_from_jetson = 0 # Speed from Jetson (if M command not used)
            leftArea = 0 # Left area value (e.g., from sensor)
            rightArea = 0 # Right area value (e.g., from sensor)
            LAST_COLOR = 0 # Reset last received color
            aDiff = 0 # Area difference
            deg = 0 # Angle variable
            prevDiff = 0 # Previous difference for PID
            error = 0 # Current error for PID
            error1 = 0 # Previous error for PID
            Servo_angle = 0 # Calculated servo angle
            
            # --- mode 0: Get Starting Direction ---
            print("Entering mode=0 (Get Starting Direction), waiting for Jetson's M,<turn>,* ...") # Status message
            while mode == 0 and turn == 0: # Loop until turn direction is set
                json_obj, m_tuple, got_stop = pump_uart(s) # Pump UART for data
                
                if got_stop:
                    control_motor(0) # Stop motor
                    set_servo_angle(0) # Center servo
                    print("[HALT] STOP received (mode0)") # Halt message
                    return # Exit run() function

                if json_obj:
                    # Only update telemetry data here
                    try:
                        if "color" in json_obj:
                            LAST_COLOR = int(json_obj["color"]) # Update last color
                            if DEBUG: print("[LATCH] JSON color ->", LAST_COLOR) # Debug print
                        elif "c" in json_obj:
                            LAST_COLOR = int(json_obj["c"]) # Update last color (short key)
                            if DEBUG: print("[LATCH] JSON c ->", LAST_COLOR) # Debug print
                        extract_magenta_from_json(json_obj) # Update magenta data
                    except:
                        pass # Ignore errors
                    try:
                        if "yaw" in json_obj:
                            yaw = float(json_obj.get("yaw", yaw)) # Update yaw
                        if "angle" in json_obj:
                            angle_from_jetson = int(json_obj.get("angle", angle_from_jetson)) # Update angle
                        if "speed" in json_obj:
                            speed_from_jetson = int(json_obj.get("speed", speed_from_jetson)) # Update speed
                        if "leftArea" in json_obj:
                            leftArea = int(json_obj.get("leftArea", leftArea)) # Update left area
                        if "rightArea" in json_obj:
                            rightArea = int(json_obj.get("rightArea", rightArea)) # Update right area
                    except:
                        pass # Ignore errors

                if m_tuple:
                    candidate = m_tuple[0] # First value of M command
                    # Starting signal is 1 or 2
                    if candidate in (1, 2):
                        turn = candidate # Set turn direction
                        print("Set turn =", turn) # Confirmation message
                    else:
                        if DEBUG: print("[SKIP] M in mode0 (not turn):", m_tuple) # Debug print: skip M

                if json_obj is None and m_tuple is None:
                    time.sleep(0.01) # Sleep if no new data

            # --- Execute rotation based on turn ---
            if turn == 1:
                print("Turning right") # Right turn message
                run_encoder_Auto(500, 45, 180) # Move with encoder and turn
            else:
                print("Turning left") # Left turn message
                run_encoder_Auto(1550, 45, -200) # Move with encoder and turn

            # --- mode 1: Color Decision ---
            mode = 1 # Change mode
            LAST_COLOR = 0 # Reset last color
            color = 0 # Reset color
            print(mode, color) # Debug print
            print('Waiting for color (M,<1..6>[,<...>] or JSON {"color":n})...') # Status message

            while mode == 1 and color == 0: # Loop until color is detected
                json_obj, m_tuple, got_stop = pump_uart(s) # Pump UART for data

                if json_obj:
                    v = None # Value variable
                    try:
                        if "color" in json_obj:
                            v = int(json_obj["color"]) # Get color from JSON
                        elif "c" in json_obj:
                            v = int(json_obj["c"]) # Get color from JSON (short key)
                    except:
                        v = None # Set to None on error
                    if v is not None:
                        if 1 <= v <= 6:
                            color = v # Set color
                            LAST_COLOR = color # Update last color
                            print("[JSON] color =", color) # Confirmation message
                            break # Break the loop
                        else:
                            if DEBUG: print("[IGNORE] JSON color out of range:", v) # Debug print: ignore out of range
                    extract_magenta_from_json(json_obj) # Update magenta data

                if m_tuple:
                    first = m_tuple[0] # First value of M command
                    if 1 <= first <= 6:
                        color = first # Set color
                        LAST_COLOR = color # Update last color
                        print("[M] color =", color, "raw:", m_tuple) # Confirmation message
                        break # Break the loop
                    else:
                        if DEBUG: print("[IGNORE] M packet in mode1 (not color):", m_tuple) # Debug print: ignore M packet
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

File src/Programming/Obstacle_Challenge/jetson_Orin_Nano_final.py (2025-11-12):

# Import the time module for delays.
import time
# Import standard system, math, and concurrency libraries.
import os, sys, math, json, threading, asyncio
# Import the OpenCV library for computer vision.
import cv2
# Import NumPy for numerical operations.
import numpy as np
# Import the serial library for UART communication.
import serial 
# Import SMBus for I2C communication (used for BNO055).
from smbus2 import SMBus
# Import Jetson.GPIO for hardware pin control.
import Jetson.GPIO as GPIO
# Import custom functions from function.py (aliased as fj, though fj is not used).
import function as fj

# -------------------- Path and Utilities --------------------
# Add the current script's directory to the system path.
sys.path.append(os.path.abspath(os.path.dirname(__file__)))
# Import color range masks from the 'masks.py' file.
from masks import rMagenta, rRed, rGreen, rBlue, rOrange, rBlack
# Import all functions from 'function.py' (e.g., find_contours, max_contour).
from function import *

# =================== BNO055 (IMU) Constants ===================
# I2C address of the BNO055 sensor.
BNO055_ADDRESS = 0x28
# Register address for setting the operation mode.
BNO055_OPR_MODE_ADDR = 0x3D
# Register address for setting the power mode.
BNO055_PWR_MODE_ADDR = 0x3E
# Expected Chip ID value for BNO055.
BNO055_ID = 0xA0
# Register address for reading the Chip ID.
BNO055_CHIP_ID_ADDR = 0x00
# Register address for reading the calibration status.
BNO055_CALIB_STAT_ADDR = 0x35
# Operation mode for configuration.
OPERATION_MODE_CONFIG = 0x00
# Operation mode for 9-axis fusion (NDOF).
OPERATION_MODE_NDOF = 0x0C
# Register address for the start of Euler Heading data (LSB).
BNO055_EULER_H_LSB = 0x1A
# I2C bus number on the Jetson (Bus 7 for 40-pin header).
BNO055_BUS = 7 

# ====== Angle and Clamping Utilities ======
# Utility function to constrain a value 'v' between 'lo' and 'hi'.
def clamp(v, lo, hi):
    # Return the clamped value.
    return lo if v < lo else (hi if v > hi else v)

# Mechanical sign for steering (e.g., +1 if positive angle means right).
MECH_SIGN = +1
# The servo value (0-180) that corresponds to driving straight.
straight_const = 90

# Convert a relative angle (-90 to +90) to a servo angle (0-180).
def rel_to_servo_deg(rel_deg: int) -> int:
    # Calculate the servo angle based on the straight constant and mechanical sign.
    servo = int(round(straight_const + MECH_SIGN * rel_deg))
    # Return the clamped servo value.
    return clamp(servo, 0, 180)

# Helper function to define a relative LEFT turn angle.
def LEFT(deg=60):   return -abs(int(deg))
# Helper function to define a relative RIGHT turn angle.
def RIGHT(deg=60):  return +abs(int(deg))

# Calculate the shortest difference between two angles (e.g., target and current).
def ang_diff_deg(target_deg: float, current_deg: float) -> float:
    # Use modulo arithmetic to find the shortest path (-180 to 180).
    return ((target_deg - current_deg + 180.0) % 360.0) - 180.0

# ---- Prebuilt morphology kernels ----
# A 5x5 rectangular kernel for morphological operations.
K5 = cv2.getStructuringElement(cv2.MORPH_RECT, (5,5))
# A 3x3 rectangular kernel.
K3 = cv2.getStructuringElement(cv2.MORPH_RECT, (3,3))

# Define the serial port device name for UART.
UART_PORT = "/dev/ttyTHS0"
# Define the baud rate for UART communication.
UART_BAUDRATE = 115200

# Function to convert a PWM signal (1000-2000) to a percentage (-100 to 100).
def pwm_to_percent(pwm: int) -> int:
    # Calculate the percentage (assuming 1500 is center, 180 is the range).
    pct = round((pwm - 1500) / 180 * 100)
    # Return the clamped percentage value.
    return max(-100, min(100, pct))

# Define a class to manage UART communication (sending and receiving).
class UartHub:
    # Initialize the UartHub instance.
    def __init__(self, port=UART_PORT, baudrate=UART_BAUDRATE):
        # Store the port name.
        self.port = port
        # Store the baud rate.
        self.baudrate = baudrate
        # Initialize the serial object as None.
        self.ser = None
        # Initialize the reader thread object as None.
        self._thread = None
        # Create a threading event to signal the reader thread to stop.
        self._stop_evt = threading.Event()
        # Create an event to signal when the Pico W is ready.
        self.started_evt = threading.Event()
        # Store the last commanded steering angle.
        self._last_angle_rel = 0
        # Store the last commanded speed percentage.
        self._last_speed_pct = 0
        # Store a pending turn/color signal command.
        self._pending_turn_signal = None
        # Create a lock to ensure thread-safe writes to the serial port.
        self.lock = threading.Lock()

    # Define the method to start the UART connection and reader thread.
    def start(self):
        # Start a try-except block to handle potential serial errors.
        try:
            # Attempt to open the serial port.
            self.ser = serial.Serial(self.port, self.baudrate, timeout=0.1)
            # Print a success message.
            print(f"UART opened on {self.port} at {self.baudrate} baud.")
        # Handle exceptions if the serial port fails to open.
        except serial.SerialException as e:
            # Print the failure message.
            print(f"Failed to open serial port {self.port}: {e}")
            # Print a help message suggesting a permission fix.
            print("Please check the port name and permissions (e.g. sudo usermod -a -G dialout $USER)")
            # Exit the script with an error code.
            sys.exit(1)
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

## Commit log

2025-08-28 update Motor & Sensor Intermediate I/O controller Selection
2025-09-06 修改工作日誌
2025-10-24 1
    Corrected the name of the main controller from 'jetson orin nano' to 'Nvidia Jetson Orin Nano' for accuracy.
2025-11-03 edit updata
    [Bearing_bracket.stl, Camera_bracket.stl, Camera_mounting_plate.stl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]
2025-11-04 press Motor Selection MG513 image
2025-11-04 press Power_supply_system of Summary diagram.png
2025-11-08 upload 3D Module
    [Bearing_Seat.stl, Infrared_Bracket.stl, Lens_Bracket_Module.stl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]
2025-11-11 Update README.md
    updata UART
